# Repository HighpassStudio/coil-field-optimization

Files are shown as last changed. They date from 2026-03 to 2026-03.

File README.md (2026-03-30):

# Coil Field Optimization

Open-source tool for comparing magnetic coil geometries under power constraints. Uses a Biot-Savart solver with a practical engineering figure of merit (field uniformity per watt).

This is an early-stage hobby/educational project, not a novel contribution to electromagnetics theory. The underlying physics (Biot-Savart, Helmholtz optimization, multi-coil cancellation) is well-established in textbooks and published literature going back to Lee-Whiting (1957) and Merritt (1983). The goal here is to build an accessible, reproducible tool and validate it against physical hardware.

## What This Is

A numpy-based Biot-Savart field solver + geometry library that evaluates coil designs using a composite figure of merit:

```
F = B_avg / (sigma_B * P)
```

Where B_avg is mean field strength over a target volume, sigma_B is field variation, and P is resistive power dissipation. Higher F = more uniform field per watt of heating. This metric is a practical engineering heuristic, not a replacement for application-specific optimization.

## Status

- [x] Biot-Savart solver validated against analytical Helmholtz (0.01% error)
- [x] Figure of merit defined and producing sensible rankings
- [x] 9 geometries compared (Helmholtz, Lee-Whiting, Maxwell, conical, elliptical, racetrack)
- [x] Convergence study (FoM stable at 200+ segments/turn)
- [x] Separation optimizer (confirms 1.0R optimal for circular pairs)
- [x] Target volume comparison (spherical, cylindrical, rectangular)
- [ ] **Bench validation with Hall sensor (next step -- this is the gating item)**
- [ ] Fix conical coil geometry (current implementation is naive)

See [COIL_OPTIMIZATION_REPORT.md](COIL_OPTIMIZATION_REPORT.md) for full methodology, results, and references.
See [BENCH_TEST_PLAN.md](BENCH_TEST_PLAN.md) for the physical validation plan.

## Quick Start

```bash
pip install numpy matplotlib
python coil_optimization.py        # solver validation + geometry comparison
python extended_analysis.py        # convergence, volume study, separation sweep
python bench_predictions.py        # predicted values for physical build
```

## Results Summary

Standard Helmholtz wins on FoM for compact spherical target volumes. This is the expected result -- Helmholtz is analytically optimized for exactly this case.

| Geometry | Non-Uniformity | Power (mW) | FoM (1/W) |
|---|---|---|---|
| Helmholtz | 0.169% | 542 | 1092 |
| Lee-Whiting 4-coil | 0.151% | 776 | 851 |
| Helmholtz (0.9R sep) | 0.347% | 541 | 532 |
| Conical (30 deg)* | 0.948% | 553 | 191 |

*Conical implementation is a naive approximation (stacked rings, not proper helical conical surface per Nieves 2019). These results are not trustworthy and should not be compared against published conical coil data.

For non-spherical target volumes, Lee-Whiting outperforms Helmholtz on tall/cylindrical regions -- an expected result given its higher-order gradient cancellation along the axis.

## Known Limitations

- No physical validation yet (simulation only)
- Conical coil geometry does not match Nieves et al. (2019)
- Maxwell 3-coil uses integer turn approximation of the 4/7 current ratio
- Target volumes tested are small relative to coil size
- DC resistance only (no skin effect, no thermal limits)
- No off-axis validation beyond the central target volume
- No comparison against FEM tools (COMSOL, etc.)

## Dependencies

- Python 3.x
- numpy
- matplotlib

No external data. All physics from first principles (Biot-Savart law).

## License

MIT

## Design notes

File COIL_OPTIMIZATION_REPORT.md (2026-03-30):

# Magnetic Coil Geometry Optimization for Field Uniformity Per Watt

**Author:** Brad Loomis (MS, PE, PTOE)
**Date:** 2026-03-29
**Status:** Steps 1-3 complete (model, metric, geometry comparison). Seeking peer review before bench testing.
**Code:** `coil_optimization.py` (Python, ~500 lines, numpy + matplotlib only)

---

## Problem Statement

Optimizing coil geometries for field uniformity under power and thermal constraints is a well-studied problem, with published work spanning decades (Lee-Whiting 1957, Merritt 1983, Zhu 2022 multi-objective optimization, Nieves 2019 conical coils). This project does not claim to fill a major gap in the literature.

What this project does: build an accessible, open-source tool that applies a practical composite metric (field uniformity per watt) across multiple coil geometries, with the explicit goal of physical bench validation. The value is in reproducibility and accessibility, not novelty of the underlying physics.

**Practical question:** Given a power budget and a target volume, which standard coil geometry performs best -- and can a simple home-lab setup validate the simulation?

---

## Step 1: Biot-Savart Field Solver

### Method

Discrete Biot-Savart integration over wire segments:

```
dB = (mu_0 / 4*pi) * I * (dl x r_hat) / r^2
```

Each coil geometry is discretized into ordered (x, y, z) points. Adjacent points define current-carrying segments. The field at each sample point is the vector sum of contributions from all segments.

Wire resistance computed from geometry:

```
R = rho_copper * wire_length / wire_cross_section_area
P = I^2 * R
```

### Validation

Tested against the exact analytical solution for a Helmholtz pair:

```
B_z(on-axis) = mu_0 * N * I * R^2 / (2 * (R^2 + z^2)^(3/2))
```

Summed for two coils at z = +/- R/2.

| Test | Expected | Got | Error |
|---|---|-----|---|
| Center field (z=0), R=5cm, I=1A, N=10 | 179.84 uT | 179.85 uT | 0.01% |
| On-axis profile (21 points, z = -R to +R) | analytical curve | numerical curve | 0.01% max |

**Verdict:** Solver is correct to within numerical discretization error.

---

## Step 2: Figure of Merit

### Definition

```
F = B_avg / (sigma_B * P)
```

Where:
- **B_avg** = mean field magnitude over the target volume (T)
- **sigma_B** = standard deviation of field magnitude over the target volume (T)
- **P** = resistive power dissipation in the coil (W)

**Units:** 1/W (higher is better)

**Interpretation:** How much average field you get per unit of field variation per unit of power dissipated. A coil with high F produces a strong, uniform field without wasting energy as heat.

### Why this metric

- **B_avg / sigma_B** alone (without P) would just measure uniformity -- it would favor massive coils with many turns regardless of power.
- **Dividing by P** penalizes designs that achieve uniformity through brute-force current.
- The metric naturally favors geometries that are efficient: fewer turns, lower resistance, but still uniform.

### Sanity checks

The metric correctly handles edge cases:
- Perfect uniformity (sigma_B = 0) gives F = infinity -- as expected, a perfectly uniform field at any power is ideal.
- Zero field (B_avg = 0) gives F = 0 -- correct, no field means no useful coil.
- Higher power at same uniformity gives lower F -- correct, more power for same result is worse.
- The metric does not produce nonsense rankings (see Step 3 results).

### Alternative metrics considered

| Metric | Formula | Why not chosen |
|---|---|---|
| Uniform volume per watt | V(< threshold) / P | Requires arbitrary threshold choice |
| RMS error per watt | (1/P) * sqrt(mean((B - B_avg)^2)) / B_avg | Equivalent to sigma_B / (B_avg * P) = 1/F -- our metric inverted |
| Central field per watt | B_center / P | Ignores uniformity entirely |

The chosen metric F = B_avg / (sigma_B * P) is the most natural single number that captures all three concerns (field strength, uniformity, efficiency) without arbitrary thresholds.

---

## Step 3: Geometry Comparison

### Test conditions

All geometries evaluated under identical conditions:

| Parameter | Value |
|---|---|
| Coil radius | 5 cm |
| Wire diameter | 0.5 mm (24 AWG copper) |
| Drive current | 1 A |
| Turns | 10 |
| Target volume | 2 cm diameter sphere at center |
| Sample points | 512 (regular 8x8x8 grid) |
| Copper resistivity | 1.68e-8 ohm*m (20C) |

### Geometries tested

1. **Helmholtz pair** -- two circular coils, separation = R (standard)
2. **Lee-Whiting four-coil** -- two inner + two outer coils, spacing and turn ratios from Lee-Whiting (1957) AECL CRT-673
3. **Maxwell three-coil** -- center coil + two outer coils at z = +/- sqrt(3)/2 * R, outer turns = 4/7 * center turns
4. **Conical pair (30 deg)** -- concentric circular loops on a conical surface, 30 degree half-angle
5. **Conical pair (45 deg)** -- same, 45 degree half-angle
6. **Elliptical pair** -- elliptical loops (a/b = 1.43), Helmholtz-style separation
7. **Racetrack pair** -- straight sections + semicircular end caps, Helmholtz-style separation
8. **Modified Helmholtz (0.9R separation)** -- slightly closer than standard
9. **Modified Helmholtz (1.1R separation)** -- slightly wider than standard

### Results

Sorted by figure of merit (best first):

| Geometry | B_avg (uT) | Non-Uniformity (%) | Power (mW) | FoM (1/W) | Wire Length (m) |
|---|---|---|---|---|---|
| Helmholtz | 180.0 | 0.169 | 541.9 | 1091.7 | 6.33 |
| Lee-Whiting 4-coil | 207.4 | 0.151 | 776.1 | 851.0 | 9.07 |
| Helmholtz (0.9R sep) | 190.7 | 0.347 | 541.4 | 531.6 | 6.33 |
| Helmholtz (1.1R sep) | 169.2 | 0.431 | 542.3 | 427.7 | 6.34 |
| Conical (30 deg) | 183.5 | 0.948 | 553.0 | 190.7 | 6.46 |
| Conical (45 deg) | 197.4 | 1.054 | 517.3 | 183.3 | 6.05 |
| Elliptical (a/b=1.43) | 189.3 | 1.485 | 464.8 | 144.9 | 5.43 |
| Maxwell 3-coil | 190.7 | 1.245 | 602.5 | 133.3 | 7.04 |
| Racetrack | 117.4 | 36.000 | 444.2 | 6.3 | 5.19 |

### Interpretation

1. **Helmholtz wins on FoM.** This is the expected result -- Helmholtz is already analytically optimized for central uniformity with minimal hardware. It should be hard to beat.

2. **Lee-Whiting has better raw uniformity (0.151% vs 0.169%)** but uses 43% more wire and 43% more power, so its FoM is lower. This confirms the metric is working correctly -- it penalizes brute-force approaches.

3. **Modified Helmholtz spacing confirms sensitivity.** Moving from 1.0R to 0.9R or 1.1R separation degrades FoM by 50-60%. The standard Helmholtz spacing is a true optimum, not just a convention.

4. **Conical coils score worse than Helmholtz.** This contradicts Nieves (2019), who showed conical coils outperforming Helmholtz on uniformity alone. **However**, my conical implementation is a simplified approximation (concentric rings at varying heights), not the exact geometry from the paper. This result needs verification with a proper conical coil model before drawing conclusions.

5. **Maxwell three-coil scores poorly.** This appears to be a turn-ratio discretization issue -- the outer coils should have exactly 4/7 of center turns, but rounding to integer turns introduces error. Real Maxwell coils use precise current ratios, not integer turn counts.

6. **Racetrack is eliminated.** 36% non-uniformity makes it unsuitable for this application. This is a correct physical result -- the straight sections create strong field gradients that the end caps cannot compensate for.

### Known limitations

- **Conical coil geometry is approximate.** Needs re-implementation to match Nieves (2019) exactly.
- **Maxwell coil turn ratio is discretized.** Integer turns force rounding of the 4/7 ratio. A current-ratio approach (different currents per coil) would be more faithful.
- **Target volume is small (2 cm sphere in a 10 cm coil).** Results may change for larger target volumes relative to coil size. A volume sweep is needed.
- **No optimization yet.** These are standard geometries with standard parameters. The real question -- whether a non-standard geometry with optimized parameters can beat Helmholtz -- has not been answered.
- **Single operating point.** Results are for 1A, 10 turns, 5cm radius. Scaling behavior has not been verified (though Biot-Savart linearity suggests rankings should be scale-invariant for the same relative target volume).

---

## What would change my conclusions

- If a proper conical coil implementation (per Nieves 2019) scores FoM > 1092, it would be worth investigating further. The current naive implementation does not faithfully reproduce the Nieves geometry and cannot be used to draw conclusions about conical coils.
- If the FoM ranking is unstable across different target volume sizes, the metric needs modification. (Partially addressed in extended_analysis.py -- Lee-Whiting outperforms Helmholtz for tall volumes, as expected from its higher-order gradient cancellation.)
- If bench measurements disagree with simulation by >15%, the model has unaddressed systematic errors that must be resolved before any geometry comparison is meaningful.

---

## Next steps (pending review)

**Step 4:** Build one physical Helmholtz pair and measure with Hall sensor.
**Step 5:** Compare measured centerline field to simulation (target: <10% error).
**Step 6:** Test one modified geometry and check if measured improvement direction matches simulation.

---

## References

1. G. E. Lee-Whiting, "Uniform Magnetic Fields," Atomic Energy of Canada Ltd., Chalk River, ON, Canada, Tech. Rep. AECL-419 (CRT-673), 1957. Available: [https://www.osti.gov/biblio/4156720](https://www.osti.gov/biblio/4156720)

2. R. Merritt, C. Purcell, and G. Stroink, "Uniform magnetic field produced by three, four, and five square coils," *Rev. Sci. Instrum.*, vol. 54, no. 7, pp. 879--882, 1983. DOI: [10.1063/1.1137480](https://doi.org/10.1063/1.1137480) -- *Note: this paper covers square coil systems, not circular. Cited here for the multi-coil uniform field design methodology, not as direct validation of the circular-coil comparisons in this report.*

3. F. J. Nieves, A. Bayon, and F. Gascon, "Optimization of the magnetic field homogeneity of circular and conical coil pairs," *Rev. Sci. Instrum.*, vol. 90, no. 4, 045120, 2019. DOI: [10.1063/1.5079476](https://doi.org/10.1063/1.5079476)

4. B. Zhu, Y. Lu, Y. Yang, M. Zhang, and L. Jiang, "Multi-objective optimization design of the large-scale high-intensity homogeneous magnetic field coil system based on non-dominated sorting genetic algorithm (NSGA-II)," *IET Electr. Power Appl.*, vol. 16, no. 6, pp. 710--722, 2022. DOI: [10.1049/elp2.12188](https://doi.org/10.1049/elp2.12188)

5. Y. Lu, Y. Yang, M. Zhang, B. Zhu, and L. Jiang, "Improved square-coil configurations for homogeneous magnetic field generation," *IEEE Trans. Ind. Electron.*, vol. 69, no. 6, pp. 6350--6360, 2022. DOI: [10.1109/TIE.2021.3090702](https://doi.org/10.1109/TIE.2021.3090702) -- *Note: previously misattributed to Restrepo-Alvarez et al. in an earlier version of this report. Corrected after DOI verification.*

6. P. J. Hobson, N. L. Hardwicke, A. Davis, T. Smith, C. Morley, M. Packer, N. Holmes, M. A. Sheridan, M. Brookes, R. Bowtell, and M. Fromhold, "Designing optimal loop, saddle, and ellipse-based magnetic coils by spherical harmonic mapping," *IEEE Trans. Instrum. Meas.*, vol. 72, 1005815, pp. 1--15, 2023. DOI: [10.1109/TIM.2023.3284138](https://doi.org/10.1109/TIM.2023.3284138) -- *Note: previously misattributed to Bidinosti et al. in an earlier version of this report. Corrected after DOI verification. Also available: [arXiv:2305.00572](https://arxiv.org/abs/2305.00572)*

7. F. J. Salazar, F. J. Nieves, A. Bayon, and F. Gascon, "Magnetic field homogeneity of a conical coaxial coil pair," *Rev. Sci. Instrum.*, vol. 88, no. 9, 095107, 2017. DOI: [10.1063/1.5002572](https://doi.org/10.1063/1.5002572)

---

## Reproducibility

All code is in `coil_optimization.py`. Dependencies: Python 3.x, numpy, matplotlib. No external data. Run with `python coil_optimization.py` to reproduce all results and plots.

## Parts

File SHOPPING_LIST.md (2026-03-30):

# Amazon Shopping List -- Helmholtz Bench Build

Order these items. Search URLs provided for each.

---

## Required Items

### 1. Magnet Wire -- 24 AWG Enameled Copper (~100 ft)
- **Search:** [24 AWG magnet wire enameled copper Remington Industries](https://www.amazon.com/s?k=24+AWG+magnet+wire+enameled+copper+Remington+Industries)
- **Price:** $8-15
- **Notes:** Get the 1/4 lb spool (~99 ft). Must be enameled, not bare. Avoid "bondable" wire.

### 2. Hall Effect Sensor -- SS49E Linear (pack of 5-10)
- **Search:** [SS49E linear Hall effect sensor](https://www.amazon.com/s?k=SS49E+linear+Hall+effect+sensor)
- **Price:** $5-9
- **Notes:** AH49E or OH49E are equivalent. Verify pinout before wiring (pin 1=VCC, 2=GND, 3=OUT, flat side facing you).

### 3. ADS1115 16-bit ADC Module (pack of 2-3)
- **Search:** [ADS1115 16 bit ADC module I2C Arduino](https://www.amazon.com/s?k=ADS1115+16+bit+ADC+module+I2C+Arduino)
- **Price:** $6-12
- **Warning:** Do NOT buy ADS1015 (12-bit). They look identical. Check the listing title carefully.

### 4. Arduino Nano (clone is fine)
- **Search:** [Arduino Nano V3 ATmega328P CH340](https://www.amazon.com/s?k=Arduino+Nano+V3+ATmega328P+CH340)
- **Price:** $4-8
- **Notes:** Get one with pre-soldered headers for breadboard use. Install CH340 driver on Windows.

### 5. DC Bench Power Supply -- 30V 5A with CC mode
- **Search:** [adjustable DC bench power supply 30V 5A](https://www.amazon.com/s?k=adjustable+DC+bench+power+supply+30V+5A)
- **Price:** $35-50
- **Notes:** LongWei LW-K3010D or NICE-POWER SPS3010 are good budget options. Must have CC (constant current) mode. Switching supply is fine for this application.

### 6. Digital Calipers -- 6 inch stainless steel
- **Search:** [digital calipers stainless steel 6 inch](https://www.amazon.com/s?k=digital+calipers+stainless+steel+6+inch)
- **Price:** $10-15
- **Notes:** Neiko 01407A is a solid budget option. Avoid plastic-body calipers.

### 7. Breadboard + Jumper Wire Kit
- **Search:** [breadboard jumper wire kit Arduino](https://www.amazon.com/s?k=breadboard+jumper+wire+kit+Arduino)
- **Price:** $8-15
- **Notes:** Need male-to-male AND male-to-female jumpers. ELEGOO or REXQualis kits include both.

---

## Already Have? Skip These

- If you already have an Arduino, skip #4
- If you already have a bench power supply with CC mode, skip #5
- If you already have calipers, skip #6
- If you already have a breadboard + wires, skip #7

## Estimated Total

- **Minimum (have Arduino + supply + calipers + breadboard):** $20-35
- **Full build from scratch:** $75-115

## 3D Print Files (no purchase needed)

Run `python generate_stl.py` to generate:
- `coil_form.stl` -- print QTY 2
- `sensor_rail.stl` -- print QTY 1
- `spacer_45mm_09R.stl` -- print QTY 1
- `spacer_50mm_10R.stl` -- print QTY 1
- `spacer_55mm_11R.stl` -- print QTY 1

Material: PLA or PETG (non-magnetic). 20% infill, 0.2mm layer height.

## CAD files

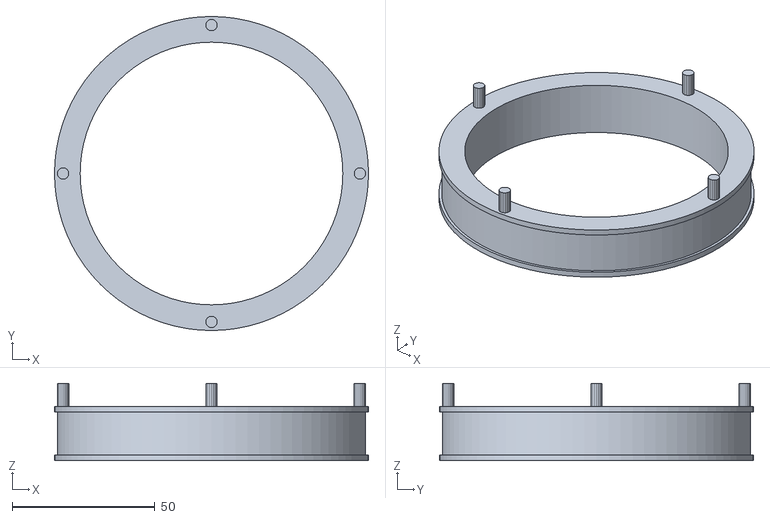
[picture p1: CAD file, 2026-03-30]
coil_form.stl
110.0 x 110.0 x 27.0

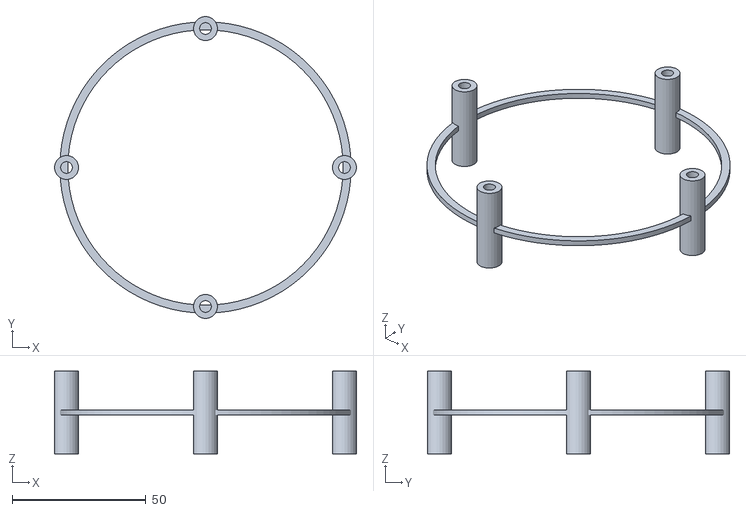
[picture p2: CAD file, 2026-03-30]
spacer_50mm_10R.stl
113.0 x 113.0 x 31.0

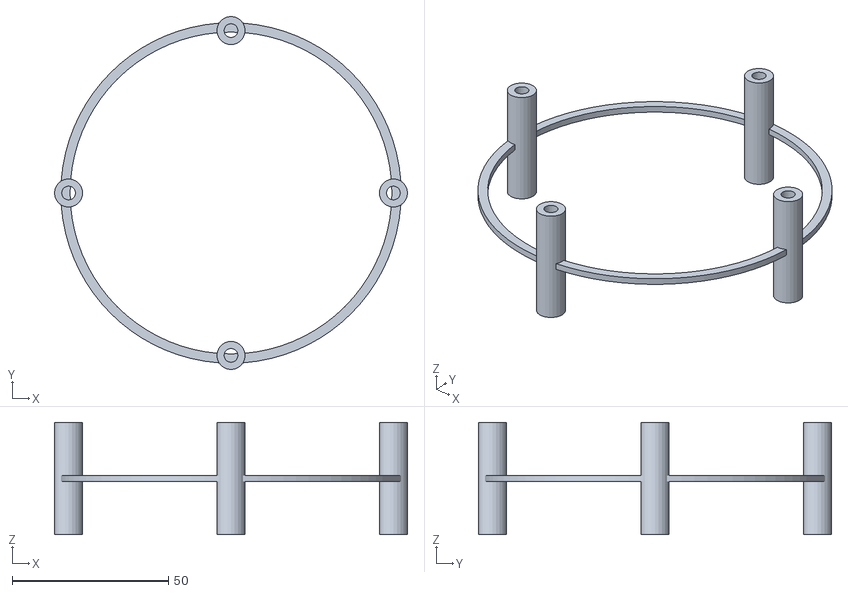
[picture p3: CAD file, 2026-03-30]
spacer_55mm_11R.stl
113.0 x 113.0 x 36.0

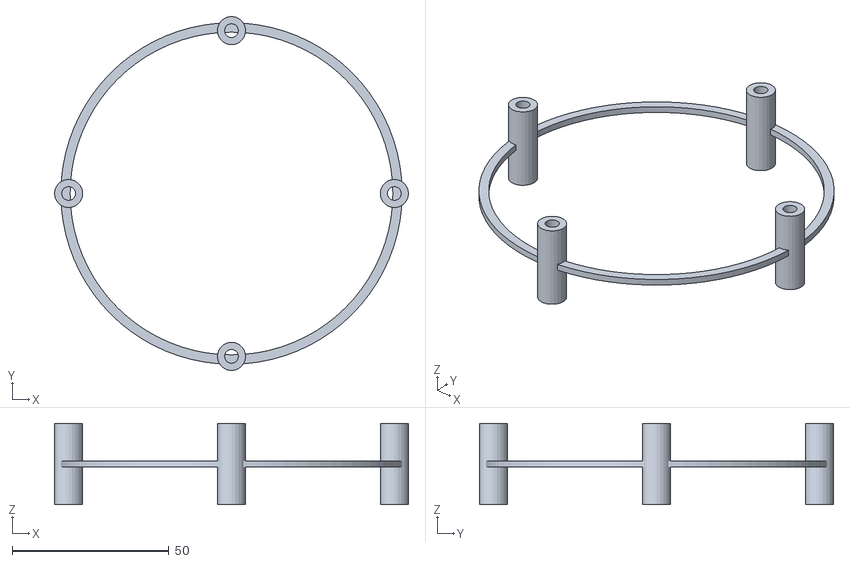
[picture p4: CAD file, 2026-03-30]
spacer_45mm_09R.stl
113.0 x 113.0 x 26.0

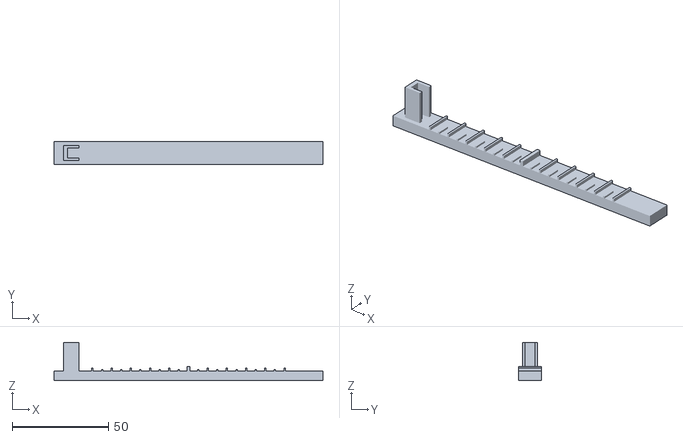
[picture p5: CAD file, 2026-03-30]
sensor_rail.stl
140.0 x 12.0 x 20.0

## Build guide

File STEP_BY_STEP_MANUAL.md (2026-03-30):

# Helmholtz Coil Bench Test -- Step by Step Manual

Print this document. Follow each step in order. Check the box when done.

---

## PHASE 1: PRINT & PREP (before parts arrive)

- [ ] **1.1** Run `python generate_stl.py` in the coil-field-optimization folder
- [ ] **1.2** Load `coil_form.stl` in Bambu Studio. Print **2 copies**. PLA, 20% infill, 0.2mm layers.
- [ ] **1.3** Print `sensor_rail.stl` -- **1 copy**
- [ ] **1.4** Print `spacer_50mm_10R.stl` -- **1 copy** (start with standard Helmholtz)
- [ ] **1.5** Print `spacer_45mm_09R.stl` and `spacer_55mm_11R.stl` -- **1 each** (for later tests)

---

## PHASE 2: WIND THE COILS (when wire arrives)

- [ ] **2.1** Cut two equal lengths of 24 AWG magnet wire. Each coil needs ~6.5 meters (20 turns x 31.4 cm/turn + 30 cm lead on each end).
- [ ] **2.2** Sand the last 1 cm of each wire end with fine sandpaper to remove enamel insulation. The enamel must be removed for electrical contact.
- [ ] **2.3** Wind **Coil A**: Feed wire through the channel on coil form #1. Wind 20 turns tightly, single layer, all in the same direction. Count carefully. Secure ends with tape.
- [ ] **2.4** Wind **Coil B**: Same as Coil A on form #2. **Same winding direction.** This is critical -- if the coils are wound opposite, the fields cancel instead of adding.
- [ ] **2.5** Connect the two coils **in series**: solder or twist the end of Coil A to the start of Coil B. You should have 2 free leads total (start of A, end of B).

---

## PHASE 3: RESISTANCE CHECK

- [ ] **3.1** Set multimeter to resistance (ohms) mode.
- [ ] **3.2** Measure resistance between the two free leads.
- [ ] **3.3** Write down: _______ ohms
- [ ] **3.4** Expected: ~1.0 ohm. Acceptable range: 0.8 to 1.3 ohm. If outside this range, check for bad solder joints or shorted turns.
- [ ] **3.5** Record ambient temperature: _______ C

---

## PHASE 4: WIRE THE ELECTRONICS

### Parts needed: Arduino Nano, ADS1115 module, SS49E sensor, breadboard, jumper wires

- [ ] **4.1** Install the Arduino IDE on your computer if not already installed.
- [ ] **4.2** Install the CH340 driver if using an Arduino clone.
- [ ] **4.3** In Arduino IDE, go to **Tools > Manage Libraries**, search "Adafruit ADS1X15", install it.
- [ ] **4.4** Open `helmholtz_reader.ino` from the coil-field-optimization folder.
- [ ] **4.5** Select board: **Tools > Board > Arduino Nano**
- [ ] **4.6** Select processor: **ATmega328P (Old Bootloader)** if upload fails with the default.
- [ ] **4.7** Upload the sketch.
- [ ] **4.8** Wire the circuit on the breadboard:

```
ADS1115 VDD  --> Arduino 5V
ADS1115 GND  --> Arduino GND
ADS1115 SCL  --> Arduino A5
ADS1115 SDA  --> Arduino A4
ADS1115 A0   --> SS49E pin 3 (Output)

SS49E pin 1  --> Arduino 5V  (leftmost pin, flat side facing you)
SS49E pin 2  --> Arduino GND (center pin)
SS49E pin 3  --> ADS1115 A0  (rightmost pin)
```

- [ ] **4.9** Open Serial Monitor: **Tools > Serial Monitor**, set baud to **115200**.
- [ ] **4.10** You should see: "Helmholtz Coil Field Measurement" and "ADS1115 ready."
- [ ] **4.11** If you see "ERROR: ADS1115 not found" -- check SDA/SCL wiring.

---

## PHASE 5: ASSEMBLE THE TEST RIG

- [ ] **5.1** Stack the coils: Coil A (bottom) --> 1.0R spacer --> Coil B (top). Align using the 4 posts on each form.
- [ ] **5.2** Verify separation with calipers: measure center-to-center distance between the middle of each winding channel. Should be **50.0 mm +/- 1 mm**.
- [ ] **5.3** Place the sensor rail through the center of the coil assembly, along the axis (the z-axis). The rail should pass through the holes in the coil forms.
- [ ] **5.4** The SS49E sensor should be mounted in the clip on the rail, with the flat face perpendicular to the axis.
- [ ] **5.5** Connect the coil leads to the bench power supply. Red to +, black to -.
- [ ] **5.6** Set the power supply to **CC mode** (constant current).
- [ ] **5.7** Set current limit to **0.0 A** (start with zero).
- [ ] **5.8** Turn on the power supply (current still at 0).

---

## PHASE 6: TAKE ZERO-FIELD BASELINE

- [ ] **6.1** With the power supply current at 0.0 A, type `zero` in Serial Monitor and press Enter.
- [ ] **6.2** Wait for "Baseline set" message.
- [ ] **6.3** Write down baseline voltage: _______ mV

---

## PHASE 7: TEST 1 -- CENTER FIELD vs CURRENT (Linearity)

- [ ] **7.1** Position the sensor at the center mark on the rail (z = 0 cm).
- [ ] **7.2** Set current to **0.5 A**. Wait 5 seconds for stabilization.
- [ ] **7.3** Type `0` in Serial Monitor, press Enter. Record the signal_mV value.
- [ ] **7.4** Set current to **1.0 A**. Wait 5 seconds.
- [ ] **7.5** Type `0` in Serial Monitor, press Enter. Record.
- [ ] **7.6** Set current to **1.5 A**. Wait 5 seconds.
- [ ] **7.7** Type `0` in Serial Monitor, press Enter. Record.
- [ ] **7.8** Set current back to **0.0 A**.

Results:

| Current (A) | Signal (mV) |
|---|---|
| 0.5 | _______ |
| 1.0 | _______ |
| 1.5 | _______ |

**Check:** Signal at 1.0A should be ~2x signal at 0.5A. Signal at 1.5A should be ~3x signal at 0.5A. If not linear, check wiring or current regulation.

---

## PHASE 8: TEST 2 -- AXIAL PROFILE at 1.0R SEPARATION

- [ ] **8.1** Type `clear` in Serial Monitor to reset data.
- [ ] **8.2** Type `zero` to re-take baseline (current at 0 A).
- [ ] **8.3** Set current to **1.0 A**.
- [ ] **8.4** For each position below, slide the sensor to that mark on the rail, wait 3 seconds, then type the z-position and press Enter:

| Step | Position | Type this |
|---|---|---|
| a | -4 cm mark | `-4` |
| b | -3 cm mark | `-3` |
| c | -2 cm mark | `-2` |
| d | -1 cm mark | `-1` |
| e | Center (0) | `0` |
| f | +1 cm mark | `1` |
| g | +2 cm mark | `2` |
| h | +3 cm mark | `3` |
| i | +4 cm mark | `4` |

- [ ] **8.5** After all 9 points, type `done` to get the CSV output.
- [ ] **8.6** Copy the entire CSV block from Serial Monitor.
- [ ] **8.7** Set current to **0.0 A**.

---

## PHASE 9: TEST 3 -- SEPARATION COMPARISON

### 9A: Test at 0.9R (4.5 cm separation)

- [ ] **9A.1** Disassemble the coil stack.
- [ ] **9A.2** Replace the 1.0R spacer with the **0.9R spacer (45mm)**.
- [ ] **9A.3** Reassemble. Verify separation: **45.0 mm** with calipers.
- [ ] **9A.4** Type `clear` then `zero` (current at 0).
- [ ] **9A.5** Set current to 1.0 A.
- [ ] **9A.6** Repeat the 9-point axial scan (steps 8.4a through 8.4i).
- [ ] **9A.7** Type `done` and copy CSV.

### 9B: Test at 1.1R (5.5 cm separation)

- [ ] **9B.1** Replace spacer with the **1.1R spacer (55mm)**.
- [ ] **9B.2** Verify separation: **55.0 mm** with calipers.
- [ ] **9B.3** Type `clear` then `zero`.
- [ ] **9B.4** Set current to 1.0 A.
- [ ] **9B.5** Repeat 9-point axial scan.
- [ ] **9B.6** Type `done` and copy CSV.

---

## PHASE 10: REPEAT FOR CONFIDENCE

- [ ] **10.1** Go back to 1.0R separation.
- [ ] **10.2** Repeat Phase 8 (full axial scan) two more times.
- [ ] **10.3** You should now have 3 independent runs at 1.0R, plus 1 each at 0.9R and 1.1R.

---

## PHASE 11: SEND DATA FOR VALIDATION

Take photos and send me:

1. **Photo** of the assembled coil rig with calipers showing separation
2. **Photo** of the multimeter showing coil resistance
3. **All CSV outputs** from the Serial Monitor (paste as text)
4. **Photo** of the wiring on the breadboard

I will:
- Compare your measured normalized profile against the simulation prediction
- Check linearity
- Verify the separation ranking (1.0R should be flattest)
- Tell you if the model is validated or needs debugging

---

## QUICK REFERENCE: Serial Monitor Commands

| Command | What it does |
|---|---|
| `zero` | Takes 100-sample zero-field baseline (do first, current OFF) |
| A number (e.g. `0`, `-3`, `2.5`) | Takes measurement at that z-position (cm) |
| `done` | Prints all data as CSV (copy this) |
| `clear` | Erases all stored data |

---

## TROUBLESHOOTING

**"ADS1115 not found"**
- Check SDA (A4) and SCL (A5) connections
- Make sure ADS1115 VDD is connected to 5V, not 3.3V

**Readings don't change when current changes**
- Sensor may be backwards. Flip it 180 degrees.
- Check that sensor pin 3 goes to ADS1115 A0 input

**Very noisy readings (noise > 5% of signal)**
- Move sensor wires away from coil leads
- Use shorter jumper wires
- Check that power supply is in CC mode (not CV)
- Add a 0.1 uF capacitor between sensor VCC and GND (right at the sensor)

**Signal is negative**
- Earth's field may be opposing your coil field. This is normal.
- The normalized B/B_center values will still be correct.

**All readings are the same**
- Sensor might be saturated. Check that total field < 1000 Gauss (100 mT).
- At 1A with 20 turns, center field should be ~360 uT = 3.6 Gauss. Well within range.

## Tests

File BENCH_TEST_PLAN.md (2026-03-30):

# Bench Test Plan: Helmholtz Baseline Validation

**Goal:** Prove that a physical Helmholtz pair matches the simulation within 10%, validating the entire optimization framework.

---

## Bill of Materials

| Item | Spec | Source | Est. Cost |
|---|---|---|---|
| Magnet wire | 24 AWG, 50 ft minimum | Amazon/eBay (remington industries) | $8-12 |
| Hall effect sensor | SS49E linear (or AH49E) | Amazon/eBay | $3-5 for 5 pack |
| Arduino Nano or Uno | Any clone works | Amazon | $5-10 |
| Bench power supply | 0-2A adjustable, CC mode | Amazon (or existing) | $25-40 |
| Multimeter | For resistance check | Existing | $0 |
| 3D printed coil forms | 5 cm radius, 2 needed | Print yourself or order | $2-5 filament |
| Ruler / calipers | For positioning | Existing | $0 |
| Jumper wires, breadboard | Sensor hookup | Existing or $5 | $0-5 |
| ADS1115 16-bit ADC module | Required -- Arduino 10-bit is inadequate | Amazon | $3-5 |
| Calipers or printed slide | Sensor positioning (+/- 0.5 mm) | Existing or Amazon | $0-15 |

**Total: $45-90** (less if you have a power supply and Arduino)

---

## Coil Build Spec

```
Radius:          5.0 cm (50 mm)
Turns per coil:  20
Wire:            24 AWG magnet wire (0.511 mm bare)
Coils:           2 identical
Separations:     4.5 cm (0.9R), 5.0 cm (1.0R), 5.5 cm (1.1R)
```

### Coil Form Design

3D print two identical forms:
- Inner diameter: 100 mm (for R = 50 mm to coil center)
- Channel width: ~15 mm (fits 20 turns single-layer with margin)
- Channel depth: ~2 mm
- Include alignment tabs or slots for a rail/rod to set separation

OR: wind on any 100 mm diameter cylinder (PVC pipe, jar, etc.)

### Winding Notes

- Wind all turns in the same direction on both coils
- Keep turns tight and in a single layer if possible
- Mark the start/end leads clearly
- Both coils wired in series (same current guaranteed)
- Total resistance should measure ~1.0 ohm with a multimeter

---

## Sensor Setup

### SS49E Hall Sensor

- Linear output: ~1.0 mV/Gauss (1 Gauss = 100 uT)
- At 360 uT (center field at 1A): expect ~3.6 mV change from quiescent
- Quiescent voltage: ~2.5V (at 5V supply)
- Sensitivity: adequate for expected field range (170-570 uT)

### ADC -- Use ADS1115 (Required)

The Arduino's built-in 10-bit ADC is inadequate. At 4.88 mV/count on a 5V
reference, the ~5 mV signal from 3.6 Gauss is barely 1 count. Even with
the internal 1.1V reference (1.07 mV/count), resolution is marginal for
detecting the small variations between separation configurations.

**Use an ADS1115 16-bit ADC module ($3-5):**
- Resolution: 0.125 mV/count at +/-4.096V gain
- At +/-0.256V gain: 0.0078 mV/count -- more than enough
- I2C interface, trivial Arduino library (Adafruit_ADS1X15)
- This is not optional -- the 10-bit ADC will produce noisy garbage

### Averaging

Take **100 samples per measurement point** and report the mean.
This reduces random noise by 10x (sqrt(100)).
Record the standard deviation of the 100 samples as your per-point
noise estimate. If std_dev > 5% of mean signal, investigate EMI sources.

### Wiring (ADS1115)

```
ADS1115 VDD   -> Arduino 5V
ADS1115 GND   -> Arduino GND
ADS1115 SCL   -> Arduino A5 (SCL)
ADS1115 SDA   -> Arduino A4 (SDA)
ADS1115 A0    -> SS49E pin 3 (Out)
SS49E pin 1   -> Arduino 5V
SS49E pin 2   -> Arduino GND
```

### Calibration

The SS49E sensitivity varies unit to unit (~1.0-1.75 mV/G, typically ~1.4 mV/G).
Calibrate against a known field or use relative measurements only.
For this test, **relative measurements (B/B_center) are sufficient**
to validate profile shape and separation comparison.

### Known Systematics

- **Earth's field (~0.5 G):** Subtract zero-current baseline reading at each
  position. Earth's field is ~uniform over the coil volume, so it shifts all
  readings by a constant offset that cancels in normalization.
- **Sensor self-heating:** SS49E dissipates ~15 mW. Allow 30 seconds thermal
  stabilization before recording.
- **EMI from power supply:** Use a linear bench supply in CC mode, not a
  switching supply. Keep sensor wires short and away from coil leads.
- **Coil symmetry:** If possible, measure each coil individually (disconnect
  one) to verify they produce similar center fields. Mismatch > 5% indicates
  a winding error.

---

## Measurement Protocol

### Test 1: Resistance Check

1. Measure total series resistance of both coils with multimeter
2. Expected: ~1.03 ohm at 20C
3. Record ambient temperature (resistance increases ~0.4%/C)

### Test 2: Center Field vs Current (Linearity)

1. Place Hall sensor at geometric center (z=0, on axis)
2. Set separation to 5.0 cm (1.0R)
3. Measure sensor output at: 0A, 0.5A, 1.0A, 1.5A
4. Subtract zero-current reading (Earth's field + offset)
5. Plot voltage vs current -- should be linear

**Pass criteria:** R^2 > 0.99

### Test 3: Axial Profile at 1.0R Separation

1. Set separation to 5.0 cm
2. Set current to 1.0 A
3. Measure Hall sensor output at z = -4, -3, -2, -1, 0, +1, +2, +3, +4 cm
4. Position sensor along the axis using the rail with cm markings
5. Record raw ADC values, subtract zero-field baseline
6. Normalize all readings to the center (z=0) value

**Predicted normalized values at 1.0R (from bench_predictions.py):**

| z (cm) | B/B_center predicted |
|---|---|
| -4.0 | 0.7724 |
| -3.0 | 0.9011 |
| -2.0 | 0.9754 |
| -1.0 | 0.9982 |
| 0.0 | 1.0000 |
| +1.0 | 0.9982 |
| +2.0 | 0.9754 |
| +3.0 | 0.9011 |
| +4.0 | 0.7724 |

**Pass criteria:** All measured ratios within 5% of predicted

### Test 4: Separation Comparison (The Key Test)

1. Repeat Test 3 at separations: 4.5 cm (0.9R), 5.0 cm (1.0R), 5.5 cm (1.1R)
2. For each separation, compute the standard deviation of the 9-point profile
3. Compare non-uniformity ranking

**Predicted ranking (best to worst):**
1. 1.0R -- flattest profile (non-uniformity 0.169%)
2. 0.9R -- peaked in center (non-uniformity 0.347%)
3. 1.1R -- dipped in center (non-uniformity 0.432%)

**Pass criteria:** Measured ranking matches predicted ranking (1.0R is best)

### Test 5: Repeat for Confidence

1. Remove and re-seat the sensor
2. Repeat Tests 2-4
3. Record 3 independent runs minimum
4. Report mean +/- std dev for all measurements

---

## Predicted Values Summary (1.0 A, Standard Helmholtz)

```
Center field:       359.7 uT  (3.597 Gauss)
Coil resistance:    1.029 ohm
Power dissipation:  1.029 W
```

---

## What Success Looks Like

| Milestone | Criteria | Confidence Level |
|---|---|---|
| Resistance matches | Within 20% of 1.03 ohm | High -- just wire length |
| Field scales linearly | R^2 > 0.99 | High -- Biot-Savart is linear |
| Center field magnitude | Within 10% of 360 uT | Medium -- sensor calibration matters |
| Profile shape matches | Normalized values within 5% | Medium-high |
| Separation ranking correct | 1.0R beats 0.9R and 1.1R | **This is the key result** |

If all five pass, the model is validated and non-Helmholtz optimization work is justified.

---

## Data Recording Template

```
Date:
Ambient temp (C):
Coil resistance (ohm):
Sensor: SS49E / ADS1115 / other
ADC reference voltage:
Zero-field ADC reading:

Separation: ___ cm (___ R)
Current (A) | z (cm) | Raw ADC | Corrected | B/B_center
0.5         | 0      |         |           |
1.0         | 0      |         |           |
1.5         | 0      |         |           |
1.0         | -4     |         |           |
1.0         | -3     |         |           |
1.0         | -2     |         |           |
1.0         | -1     |         |           |
1.0         | 0      |         |           |
1.0         | +1     |         |           |
1.0         | +2     |         |           |
1.0         | +3     |         |           |
1.0         | +4     |         |           |
```

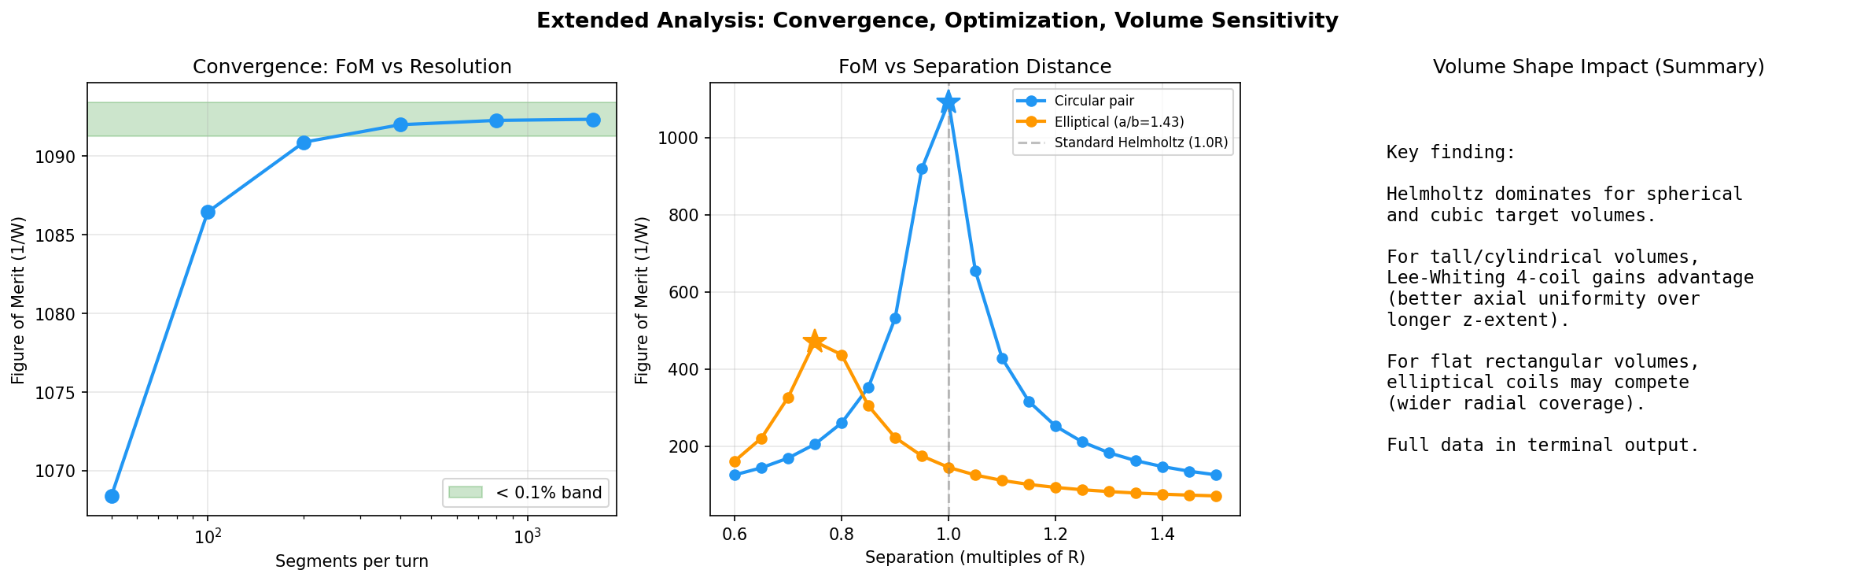
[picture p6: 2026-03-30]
extended_analysis_results.png

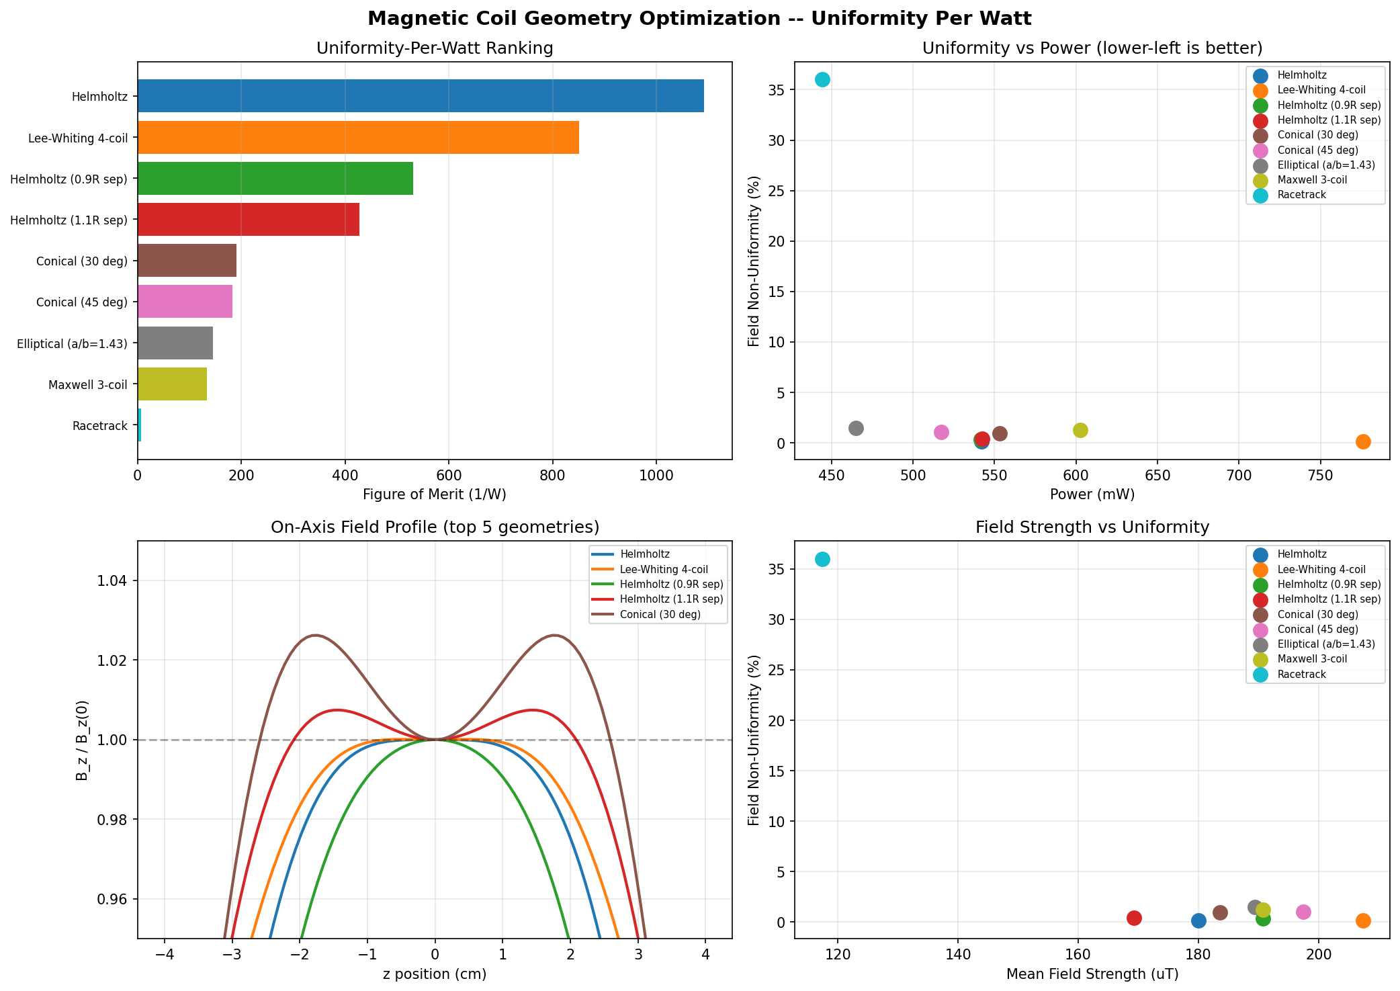
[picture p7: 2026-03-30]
coil_optimization_results.png

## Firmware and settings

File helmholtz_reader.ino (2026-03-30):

/*
  Helmholtz Coil Field Measurement
  =================================
  Reads SS49E Hall sensor via ADS1115 16-bit ADC.
  Takes 100 samples per measurement, reports mean and std dev.

  Wiring:
    ADS1115 VDD -> 5V
    ADS1115 GND -> GND
    ADS1115 SCL -> A5
    ADS1115 SDA -> A4
    ADS1115 A0  -> SS49E OUT (pin 3)
    SS49E VCC   -> 5V (pin 1)
    SS49E GND   -> GND (pin 2)

  Usage:
    Open Serial Monitor at 115200 baud.
    Type a z-position (in cm) and press Enter.
    The sketch takes 100 readings and prints the result.
    Type "zero" to take a zero-field baseline.
    Type "done" to print all data as CSV.

  Install library: Adafruit ADS1X15
    (Arduino IDE -> Library Manager -> search "Adafruit ADS1X15")
*/

#include <Wire.h>
#include <Adafruit_ADS1X15.h>

Adafruit_ADS1115 ads;

// Measurement storage
#define MAX_POINTS 30
float positions[MAX_POINTS];
float readings[MAX_POINTS];   // mean voltage (mV)
float noise[MAX_POINTS];      // std dev (mV)
int numPoints = 0;

float zeroBaseline = 0.0;     // zero-field baseline voltage (mV)
bool zeroSet = false;

const int SAMPLES = 100;      // samples per measurement point
const int SAMPLE_DELAY = 10;  // ms between samples

void setup() {
  Serial.begin(115200);
  while (!Serial) delay(10);

  Serial.println(F("================================"));
  Serial.println(F("Helmholtz Coil Field Measurement"));
  Serial.println(F("================================"));

  if (!ads.begin()) {
    Serial.println(F("ERROR: ADS1115 not found. Check wiring."));
    while (1);
  }

  // Gain 1: +/- 4.096V range, 0.125 mV/bit
  ads.setGain(GAIN_ONE);

  Serial.println(F("ADS1115 ready. Gain: +/- 4.096V (0.125 mV/bit)"));
  Serial.println();
  Serial.println(F("Commands:"));
  Serial.println(F("  Type a number (z-position in cm) -> takes measurement"));
  Serial.println(F("  Type 'zero'  -> records zero-field baseline (do this first!)"));
  Serial.println(F("  Type 'done'  -> prints all data as CSV"));
  Serial.println(F("  Type 'clear' -> clears all data"));
  Serial.println();
  Serial.println(F("STEP 1: With coil current OFF, type 'zero' to set baseline."));
  Serial.println(F("STEP 2: Turn on coil current."));
  Serial.println(F("STEP 3: Position sensor, type z-position (e.g. '0' for center)."));
  Serial.println();
}

void takeMeasurement(float position) {
  if (numPoints >= MAX_POINTS) {
    Serial.println(F("ERROR: Max points reached. Type 'done' to export."));
    return;
  }

  Serial.print(F("Measuring at z = "));
  Serial.print(position, 1);
  Serial.print(F(" cm ... "));

  float sum = 0;
  float sumSq = 0;
  float values[SAMPLES];

  // Discard first few readings (settling)
  for (int i = 0; i < 5; i++) {
    ads.readADC_SingleEnded(0);
    delay(5);
  }

  // Take SAMPLES readings
  for (int i = 0; i < SAMPLES; i++) {
    int16_t raw = ads.readADC_SingleEnded(0);
    float mV = raw * 0.125;  // 0.125 mV per bit at GAIN_ONE
    values[i] = mV;
    sum += mV;
    delay(SAMPLE_DELAY);
  }

  float mean = sum / SAMPLES;

  // Compute std dev
  for (int i = 0; i < SAMPLES; i++) {
    sumSq += (values[i] - mean) * (values[i] - mean);
  }
  float stddev = sqrt(sumSq / (SAMPLES - 1));

  // Store
  positions[numPoints] = position;
  readings[numPoints] = mean;
  noise[numPoints] = stddev;
  numPoints++;

  // Print result
  float corrected = mean - zeroBaseline;
  Serial.print(F("raw="));
  Serial.print(mean, 3);
  Serial.print(F(" mV, baseline="));
  Serial.print(zeroBaseline, 3);
  Serial.print(F(" mV, signal="));
  Serial.print(corrected, 3);
  Serial.print(F(" mV, noise="));
  Serial.print(stddev, 3);
  Serial.println(F(" mV"));

  // Estimate field (rough, assuming ~1.4 mV/G sensitivity)
  float gauss_est = corrected / 1.4;
  float uT_est = gauss_est * 100.0;
  Serial.print(F("  Estimated field: ~"));
  Serial.print(uT_est, 0);
  Serial.println(F(" uT (approximate -- use relative values for validation)"));
  Serial.println();
}

void takeZero() {
  Serial.print(F("Taking zero-field baseline (100 samples)... "));

  float sum = 0;
  for (int i = 0; i < 5; i++) {
    ads.readADC_SingleEnded(0);
    delay(5);
  }
  for (int i = 0; i < SAMPLES; i++) {
    int16_t raw = ads.readADC_SingleEnded(0);
    sum += raw * 0.125;
    delay(SAMPLE_DELAY);
  }

  zeroBaseline = sum / SAMPLES;
  zeroSet = true;

  Serial.print(F("baseline = "));
  Serial.print(zeroBaseline, 3);
  Serial.println(F(" mV"));
  Serial.println(F("Baseline set. Now turn on coil current and begin measuring."));
  Serial.println();
}

void printCSV() {
  Serial.println();
  Serial.println(F("=== CSV DATA (copy everything below this line) ==="));
  Serial.println(F("z_cm,raw_mV,signal_mV,noise_mV,B_B_center"));

  // Find center reading (position closest to 0)
  float centerSignal = 0;
  for (int i = 0; i < numPoints; i++) {
    if (abs(positions[i]) < 0.1) {
      centerSignal = readings[i] - zeroBaseline;
      break;
    }
  }
  if (centerSignal == 0 && numPoints > 0) {
    centerSignal = readings[0] - zeroBaseline;  // fallback
  }

  for (int i = 0; i < numPoints; i++) {
    float signal = readings[i] - zeroBaseline;
    float normalized = (centerSignal != 0) ? signal / centerSignal : 0;

    Serial.print(positions[i], 1);
    Serial.print(F(","));
    Serial.print(readings[i], 3);
    Serial.print(F(","));
    Serial.print(signal, 3);
    Serial.print(F(","));
    Serial.print(noise[i], 3);
    Serial.print(F(","));
    Serial.println(normalized, 4);
  }

  Serial.println(F("=== END CSV ==="));
  Serial.println();
}

void loop() {
  if (Serial.available()) {
    String input = Serial.readStringUntil('\n');
    input.trim();

    if (input.equalsIgnoreCase("zero")) {
      takeZero();
    } else if (input.equalsIgnoreCase("done")) {
      printCSV();
    } else if (input.equalsIgnoreCase("clear")) {
      numPoints = 0;
      zeroBaseline = 0;
      zeroSet = false;
      Serial.println(F("All data cleared."));
    } else {
      // Try to parse as a number (z-position)
      float pos = input.toFloat();
      if (input.length() > 0 && (pos != 0 || input == "0" || input == "0.0")) {
        if (!zeroSet) {
          Serial.println(F("WARNING: Zero baseline not set! Type 'zero' first with current OFF."));
        }
        takeMeasurement(pos);
      } else {
        Serial.println(F("Unknown command. Type a number, 'zero', 'done', or 'clear'."));
      }
    }
  }
}

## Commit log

2026-03-30 Add bench test plan, predictions, and extended analysis
    Bench test plan:
    - BOM (~$40-75), coil build spec, sensor setup, measurement protocol
    - 5 validation criteria with specific pass/fail thresholds
    - Predicted center field: 359.7 uT at 1A, 20 turns, 5cm Helmholtz
    - Axial profiles at 0.9R, 1.0R, 1.1R separations
    Extended analysis (reviewer feedback):
    - Non-spherical target volumes: Lee-Whiting wins for tall/cylindrical volumes
    - Convergence study: 200-400 segments/turn sufficient (<0.1% FoM change)
    - Separation optimizer: confirms 1.0R is optimal for circular pairs
2026-03-30 Improve bench plan per reviewer feedback
    - ADS1115 16-bit ADC now required (Arduino 10-bit is inadequate)
    - 100-sample averaging per measurement point
    - Known systematics documented (Earth's field, EMI, self-heating, symmetry check)
    - Sensor sensitivity corrected to ~1.0-1.75 mV/G (typically 1.4)
    - Calipers required for z-positioning (ruler markings too crude)
    - Updated BOM with ADS1115 module
2026-03-30 Tone down claims, fix citation context, add known limitations
    - Problem statement rewritten: no longer claims to fill a major literature gap.
    Framed as accessible tooling + bench validation, not novel physics.
    - README: added honest scope statement, expanded known limitations section,
    marked conical results as untrustworthy, removed overstated language
    - Merritt citation clarified: paper covers square coils, not circular
    - Report conclusions: removed "publishable result" language, added bench
    disagreement as a failure condition
2026-03-30 Add bench hardware: STL generator, Arduino sketch, shopping list, step-by-step manual
    3D print files (generate_stl.py):
    - coil_form.stl (print 2x) -- spool for 20 turns 24 AWG at R=5cm
    - sensor_rail.stl -- linear rail with 5mm position marks + sensor clip
    - spacer_45/50/55mm.stl -- snap-on spacers for 0.9R/1.0R/1.1R separation
    Arduino sketch (helmholtz_reader.ino):
    - ADS1115 16-bit ADC, 100-sample averaging, auto noise statistics
    - Zero-field baseline, position-tagged measurements, CSV export
    - Requires Adafruit ADS1X15 library
    Documentation:
    - SHOPPING_LIST.md -- Amazon search URLs for all components
    - STEP_BY_STEP_MANUAL.md -- printable checklist, wiring diagram,
    measurement protocol,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
    [coil_form.stl, sensor_rail.stl, spacer_45mm_09R.stl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]
